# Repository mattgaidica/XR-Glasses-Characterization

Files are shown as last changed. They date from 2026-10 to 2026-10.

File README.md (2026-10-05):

# XR glasses characterization

Pipeline for controlled ocular photostimulation on a consumer see-through XR display (VITURE Luma Ultra): the stimulus application, the UPRtek acquisition and settings-to-exposure model, the calibration package, and the measurement data.

The validation manuscript and the scripts that rebuild it are not in this repository. Neither are the lab documents or the HOSI spectrometer pipeline.

## What is here

| Path | What it is |
|---|---|
| `apps/chronolume_host/` | Stimulus application. Build instructions are in its README. |
| `analysis/uprtek/` | UPRtek MK350S acquisition and the settings-to-exposure model. |
| `data/uprtek/model/` | Calibration package (`calibration.json`), validation report, and the [developer usage guide](data/uprtek/model/README.md). |
| `data/uprtek/` | The characterization, model, frame, and grid sessions. |
| `data/sessions/` | Host event logs for the characterization sessions. |
| `3d/` | Meter model (STEP). Added separately; this packaging script does not create it. |

`vendor/viture/` (the VITURE SDK) is not included. The host application links against it; see `apps/chronolume_host/README.md` and [VITURE](https://www.viture.com).

The mixture sessions `model_mixtures_s1_20261005_115533` and `model_mixtures_s2_20261005_120222` are included because `calibration.json` lists them in `training_sessions`. Earlier sessions from 2026-10-02 and 2026-10-03 are not: nothing in the manifest or the calibration package uses them.

## Run the analysis

Requires Python 3.11+.

```bash
python3 -m pip install -e "analysis/uprtek[analysis,dev]"
cd analysis/uprtek && python3 -m pytest
```

Predicting a uniform stimulus from the calibration package is described in `data/uprtek/model/README.md`.

## License

MIT. See `LICENSE`. The CIE tables under `analysis/uprtek/src/uprtek/data/cie/` stay under their own terms (`ATTRIBUTION.md` in that folder).

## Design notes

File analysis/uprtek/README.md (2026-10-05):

# Chronolume UPRtek capture and analysis

Automated spectral sweeps of the VITURE glasses with a UPRtek MK350S (Premium) on Windows, plus offline analysis.
This package is **independent of `analysis/hosi/`**: it imports nothing from HOSI and HOSI imports nothing from it. The CIE tables in `src/uprtek/data/cie/` are unchanged copies.

## What differs from HOSI

| | HOSI (`analysis/hosi`) | UPRtek (`analysis/uprtek`) |
|---|---|---|
| Raw data | C12880MA counts, per-row darks | Factory-calibrated spectral irradiance, 380–780 nm at 1 nm |
| Quantity | Radiance through lens/tube | Cosine-corrected **irradiance** at the probe plane |
| Absolute scale | `radSens` + transfer calibration | Instrument factory calibration |
| Corneal irradiance / α-opic | Needs an FOV assumption | Direct, with the probe at the eye position |
| Dark | Shutter dark at matching integration time | `mk_Msr_Dark` with the sensor capped |

`mk_GetSpectrum` returns **mW·m⁻²·nm⁻¹**. Every capture is checked by integrating the spectrum against V(λ) and comparing with the meter's own lux (`computed_to_instrument_lux_ratio`; mismatch > 3 % → `UNIT_CHECK_MISMATCH`, not quantitative).

## Setup (once)

The vendor `mkusb.dll` is 32-bit, so capture runs under 32-bit Python; analysis runs under 64-bit Python. From the repository root:

```powershell
py -3.12 -m venv .venv
.\.venv\Scripts\python -m pip install -e "analysis/uprtek[analysis,dev]"

py -3.12-32 -m venv .venv32
.\.venv32\Scripts\python -m pip install -e analysis/uprtek
```

Requires uSpectrum installed (`C:\Program Files (x86)\uSpectrum`), which provides `mkusb.dll` and the SiUSBXp driver. Override the DLL folder with `UPRTEK_MKUSB_DIR` or `--mkusb-dir`. **Close uSpectrum** before capturing; the meter allows one client.

Check the meter:

```powershell
.\.venv32\Scripts\python -m uprtek.probe
```

## Run a sweep

1. Glasses connected, desktop **extended** (Win+P → Extend). HDR, Night light, and Auto color management off for the glasses display. Dark room.
2. Start the host with the control port, fullscreen on the glasses monitor (indices are printed at startup):

   ```powershell
   .\build\apps\chronolume_host\Release\chronolume_host.exe --device viture --monitor 1 --control-port 7777
   ```

   Press `P` to fullscreen (or the sweep warns you).
3. Position the probe at the eye position and run:

   ```powershell
   .\.venv32\Scripts\python -m uprtek.sweep --sequence hosi_set --calibration-version uprtek_v001 --repeats 3
   ```

   For all channels alike (red, green, white and blue ladders and brightness sweeps), use `--sequence color_set --brightness 8`; `--brightness-levels 0,4,8` shortens it.

   The sweep asks you to cap the sensor for dark calibration, then uncap. The glasses show `(0,0,255)` during dark calibration so they do not sit dark through the prompts; `session.json` records how long `mk_Msr_Dark` itself took (`dark.duration_s`). It then presents each stimulus, waits for the host to confirm the frame was presented (with framebuffer readback), dwells `--settle-s`, and captures `--repeats` spectra. Every capture is also written into the host session log as a `mark` event.

Sequences (labels match the HOSI file names):

| `--sequence` | Steps |
|---|---|
| `hosi_set` (default) | `R255 G255 B255 W255`, blue ladder `B192…B016`, `K`, then `B255_br8…B255_br0` |
| `color_set` | `R255 G255 B255 W255`, blue ladder `B192…B016`, `K`, ladders `R/G/W 192 128 064`, then `R255 G255 B255 W255` at each of `--brightness-levels` (`R255_br8 … W255_br0`; no `W255_br8`, see *White at brightness 8*), then the duty block: `R255_d42 G255_d42 B255_d42 W255_br7_d42`, then the same at duty 30 (every duty preset below the base; see *Duty cycle*) |
| `primaries` | `R255 G255 B255 W255 K` |
| `blue_ladder` | `B016 B032 B064 B128 B192 B255` at the current brightness |
| `brightness_sweep` | `B255` at `--brightness-levels` (default `0-8`), highest first |
| `repeatability` | `B128 B255` (Gate 2: rerun after 20 min) |

`K` is subtracted from every capture in analysis and the dark reading drifts upward after dark calibration (see below), so it is taken right after the dimmest blue codes rather than first; a long black stretch was also followed by blanking on the next capture. Brightness sweeps run highest level first, so from base brightness 8 the first group and the level-8 anchors need no change. `color_set` characterizes red, green and white like blue, which the dose table needs (red, green and blue at level 8, white at its maximum of 7); the gamma and brightness fits in `uprtek-report` still use only the pure-blue points.

Useful options: `--eye left|right|both`, `--exposure auto|<ms>` (manual, at most 65 ms), `--max-exposure-ms N` (auto-exposure ceiling, see below), `--priming N` (discarded captures after each stimulus change, default 1; `0` saves time; a priming capture already at the exposure ceiling is kept as repeat 0, marked `kept_as_rep0` / `from_priming`), `--max-retries N` / `--retry-wait-s S` (re-capture when the display reads dark, default 5 / 2 s, see below), `--capture-retries N` (whole-capture re-runs, default 3), `--anchor-every N` (reference capture interval, default 5; `0` disables), `--duty 98|42|30|keep` (duty cycle held for the sweep, default 98; see *Duty cycle*), `--brightness N|keep` (hardware brightness for steps without their own, i.e. primaries, ladders and `K`, default 8; those steps return to it after a brightness sweep), `--brightness-change-rgb R,G,B` (shown while brightness changes, default `0,0,0`, see below), `--warmup-s 600` (Gate 2 warm-up on `(0,0,255)`), `--manual-brightness` (prompts you if the host cannot set brightness; captures are flagged `BRIGHTNESS_MANUAL`), `--allow-mock` (testing without glasses), `--skip-dark`.
Brightness is restored and the display set to black at the end, including on Ctrl-C.

### Low light: exposure

`mk_Msr_Capture` and `mk_Msr_SetMaxExpTime` take **microseconds** (the vendor guide says ms), and the reported `exposure_time_raw` is in µs. Manual exposure is therefore capped at 65 ms by the DLL's 16-bit argument, below the 500 ms auto-exposure ceiling, so it does not help with dim stimuli. Raise the auto-exposure ceiling instead, e.g. `--max-exposure-ms 5000` (verified on MK350X FW 1.1.1.B4: 5 s exposures, light strength 0). The ceiling persists on the meter, so the sweep and probe set it at the start and always restore 500 ms at the end; each capture records `max_exposure_ms`, and `range_cause` `low` means auto-exposure hit that ceiling. The sweep runs dark calibration after setting the ceiling. Check that the dark correction holds at long exposures before trusting dim readings: `.\.venv32\Scripts\python -m uprtek.probe --dark --max-exposure-ms 5000` with the sensor left capped should read close to 0 lux.

Output:

```text
data/uprtek/session_YYYYMMDD_HHMMSS/
  session.json        meter identity, host/device, options, dark time and duration, anchors, capture list, status
  raw/B255.csv        wavelength_nm, rep0, rep1, …  (mW/m²/nm, as returned by the meter)
  raw/B255.json       RGB, eye, brightness (+ source), duty cycle, film, display mode,
                      calibration version, host frame + readback, per-repeat meter readings
```

## Analyze

```powershell
.\.venv\Scripts\chronolume-uprtek analyze data/uprtek/session_YYYYMMDD_HHMMSS
.\.venv\Scripts\chronolume-uprtek linearity data/uprtek/session_.../analysis --x blue_code
.\.venv\Scripts\chronolume-uprtek linearity data/uprtek/session_.../analysis --x brightness
.\.venv\Scripts\chronolume-uprtek linearity data/uprtek/session_.../analysis --x duty
```

`linearity --x duty` fits a line to B255 at brightness 8 against duty cycle (the duty block plus the base-duty `B255`, duplicates averaged) and reports each duty as a fraction of the highest.

`linearity --x blue_code` fits a power law `y = y(255)·(B/255)^gamma` in log-log space to the quantitative blue-ladder captures and reports gamma, R² (log space) and each point's deviation from the fit. `linearity --x brightness` reports, for the `B255_br*` captures, the ratio between consecutive measured brightness levels (a disqualified level is skipped, and the step shows which levels it spans) and each level as a fraction of the brightest. Both write `linearity_<x>.json` and `.png` in the analysis folder. Both use pure-blue captures only; red, green and white captures from `color_set` are analyzed per capture but not yet fitted.

Per capture (`analysis/<label>/`): `spectrum.csv` (W/m²/nm, std across repeats, µW/cm²/nm, photons, and the increment over `K` when present), `summary.json`, `spectrum.png`, `spectrum_normalized.png`. A session table is written to `analysis/summary.csv`.

`summary.json` uses the HOSI key names where the quantity is the same (`peak_wavelength_nm`, `measured_fwhm_nm`, `spectral_centroid_nm`, `offband_fraction_500_780`, `irradiance_430_470_uW_cm2`, `photon_irradiance_photons_cm2_s`, `melanopic_EDI_lux`, …). Band integrals are irradiance (`irradiance_380_500_W_m2`, …), not radiance. `repeat_cv_percent` is the Gate 2 repeatability across repeats.

QC flags: `OUT_OF_RANGE`, `READBACK_MISMATCH`, `UNIT_CHECK_MISMATCH`, `NO_DISPLAY_LIGHT`, `REPEAT_OUTLIER`, `DUTY_MISMATCH`, `ANCHOR_DRIFT` (these make a capture non-quantitative), `LOW_LIGHT`, `REPEAT_CV_HIGH` (> 5 %), `WEAR_NOT_WORN` (the host reported the wear sensor as not worn at a repeat), `AMBIENT_PRESENT` (black > 1 % of the measurement), `FWHM_UNRESOLVED`, `PEAK_OUTSIDE_SEARCH`, `BRIGHTNESS_MANUAL`.

`OUT_OF_RANGE` means the meter returned light strength 2. The vendor guide calls that over exposure, but the MK350X (FW 1.1.1.B4) also returns it when the signal is too weak, so each repeat records a `range_cause`: `low` (auto-exposure pinned at its maximum), `saturated` (exposure ≤ 10 ms with ≥ 1 lux), or `unknown` (in darkness auto-exposure can also drop to a few ms, reading well under 1 lux).

**Blank display.** The glasses can blank intermittently during a sweep (even right after waking them). Turn off Wearer Detection on a phantom (see `apps/chronolume_host/README.md`); it was on for all sessions before 2026-10-03, off since. When the display blanks, the meter then reads its own dark noise, usually **without** light strength 2: a spectrum peaking above ~700 nm at a few tenths of a lux, typically at the exposure ceiling. Auto-exposure itself recovers correctly from long exposures (checked by switching black → B255 with a 5 s ceiling). The display primaries peak at 459, 539 and 631 nm, so for any non-black stimulus a peak ≥ 700 nm means no display light: the sweep discards that capture, waits `--retry-wait-s`, and re-captures, up to `--max-retries` times per repeat. Discarded attempts are kept under `rejected` in the raw JSON (with the host's `wear` value) and every attempt is a `mark` event. If the retries run out the capture is flagged `NO_DISPLAY_LIGHT`. A display that turns on part-way through a long exposure gives a low, blue-shifted reading that the peak test cannot see; `REPEAT_OUTLIER` (a repeat > 30 % from the capture median, checked when the median is ≥ 0.1 lux) catches it. `--priming` discarded captures (default 1) are recorded under `priming`.

**Stimulus visibility.** Before any capture (steps, re-runs and anchors) the host's framebuffer readback must match the requested RGB on a real framebuffer. A minimized stimulus window reads back 0×0 and zeros, which would otherwise pass for black; the glasses then show the desktop, and every stimulus measures the same. On a failed readback the sweep sends `fullscreen on`, then prompts you twice, then stops with an error. Failed readbacks that were fixed are kept under `readback_fixes`. The host no longer minimizes its fullscreen window when it loses focus, so this should be rare.

**Brightness changes on black.** Every brightness change (base level, brightness steps, anchors) is made with the display showing black; the stimulus is then re-presented and its readback checked before measuring. Raising brightness to 8 while full white was showing at duty 98 dropped the glasses' USB control link twice (SDK error -3, and every later command failed until the host was restarted). `--brightness-change-rgb 0,0,16` shows a dim blue instead, to keep the panel lit; it has not yet been tested against that USB drop. The sweep asks the host for the current level first and skips the change (and `--brightness-settle-s`) when the glasses already report it.

**White at brightness 8.** Full white `(255,255,255)` at brightness 8, duty 98, makes the Luma Ultra's output collapse (the next blue anchor read 0.47× and 0.09× of the reference in two sweeps on 2026-10-03) and then drops its USB control link (`get_brightness_level` returns -7, `set_duty_cycle` -3) until the host is restarted. It happens even when brightness is changed on black first. It is not specific to Windows or to duty 98: on macOS (firmware 12.0.01.101) at duty 90 on 2026-10-04, stepping white from 7 to 8 by hand returned SDK error -3, and an earlier attempt showed white at 8 briefly before the glasses' display dropped off the system. Red, green and blue alone are fine at 8, and white at 7 is fine. The sweep therefore never shows white (`r = g = b > 0`) above `WHITE_MAX_BRIGHTNESS` = 7: white steps that follow the base level (`W255`, the `W` ladder) run at 7 when the base is 8 and the next step returns to the base; with `--brightness keep` at 8 the same cap applies; sequences that ask for white above 7 explicitly are refused before anything is shown; and `color_set` has no `W255_br8`. Capped captures carry `white_brightness_capped: true` in their raw JSON, and the console line shows `(white capped at 7)`. Whether lower white codes (`W192`, …) are safe at 8 has not been tested. The host itself does not enforce the limit, so do not show white at 8 by hand.

**Re-running captures.** A capture that ends with `NO_DISPLAY_LIGHT` or `REPEAT_OUTLIER` is re-run in full (all repeats) up to `--capture-retries` times (default 3). Both triggers come from the capture's own readings, never from comparison with an expected value, so re-running does not steer results. Every discarded attempt is kept, with its spectra, under `discarded_attempts` in the raw JSON, and `capture_attempts` records how many were needed. If the last attempt still fails, the flag stays and the capture is not quantitative.

**Anchors.** A display that stays dim for a whole capture gives repeats that agree with each other, so the outlier check cannot see it. The sweep therefore captures an anchor, (0,0,255) at brightness 8, before the first step and after every `--anchor-every` steps (default 5; `0` disables). The first anchor is the reference; it must be clean or the sweep prompts you to check the glasses (three tries, then it stops). A later anchor more than 10 % from the reference is captured once more; if it is still off, the sweep pauses so you can wake the glasses or check the probe, then re-runs the steps since the previous anchor (twice at most). If it is still off after that, those captures are flagged `ANCHOR_DRIFT` and the sweep continues. Anchors are written to `anchors/raw/` (not `raw/`, so analysis ignores them) and summarised under `anchors` in `session.json`; block re-runs are listed under `block_reruns`. With `--brightness keep` brightness is restored after each anchor; otherwise the next step sets its own level (or the base level).

**Duty cycle.** The Luma Ultra supports only the manufacturer's SDK duty presets 98, 42 and 30 (`DUTY_PRESETS` in `sequences.py`); 98 is the base duty. `--duty` takes one of them (default 98) or `keep`, which leaves the glasses alone. When the sequence has steps with their own duty (`color_set`), the sweep first runs a duty check: it requests each preset with the display black and reads it back, and stops if any is not accepted. The result (every requested and reported value) is stored as `duty_acceptance` in `session.json`, and `color_set` builds its duty block from the presets below the base. The base duty is applied before the first capture and must read back, or the sweep stops. Duty is changed only on black, followed by `--brightness-settle-s`, and the steps after the duty block return to the base duty. The host re-reads duty after every brightness change; if it moved, the sweep re-applies it and records the old value as `duty_reapplied_from`. A capture whose host state does not show the requested duty (`requested_duty_cycle` in the raw JSON) is flagged `DUTY_MISMATCH`. The initial duty is restored at the end. Duty is a real intensity knob: at B255 and brightness 8, duty 30 gave ~41 % of the duty-90 output and duty 98 ~110 %. The host keys `,` / `.` (−10 / +10) and `9` (98) set duty by hand, e.g. for a photodiode check of the emitted waveform.

**Dark drift at long exposures.** With a 5 s ceiling the capped/blank reading drifted from 0.02 to ~0.5 lux over ~15 min after dark calibration. Measure dim stimuli soon after the dark step and keep `K` in the sequence so the analysis can subtract it; the built-in sequences take `K` right after the dimmest blue codes. Sessions recorded before this change carry the old name `OVER_EXPOSED`, which is still treated as disqualifying.

## Exposure model

A settings-to-exposure model predicts corneal melanopic EDI, photopic illuminance and melanopic DER for a uniform full-frame color at a brightness level and duty cycle, without measuring it (`docs/chronolume_exposure_model_developer_spec.md`), at the SDK duty presets.

### Capture (32-bit Python)

The grid is `src/uprtek/data/model_grid_v3.json` (schema `chronolume-model-grid/2`; `--grid` selects another, e.g. `model_grid_v2.json`, which keeps level 0 in the mixtures, or `model_grid_v1.json`), in three stages:

| `--stage` | Settings | Sessions |
|---|---|---|
| `primaries` | Code ladder: R, G, B at codes 64, 192, level 8, duty 98. Crossed: R, G at codes 128, 255 × levels 4, 8 × duties 30, 42, 98; B at 128, 255 × level 8 × the same duties, and B255 at level 4 × the same duties (39) | 3 |
| `ladders` | R, G, B at codes 64, 128, 192 × levels 2, 4, 5, 7 × duty 98 (36); code ladders below level 8, added after the primaries sessions showed that the code response depends on level | 3 |
| `mixtures` | 19 two- and three-channel compositions (gray axis, full white, pairs, unequal mixes) × levels 4, 7 × duties 30, 98 (76; level 0 dropped in v3, its mixtures fall near or below the meter's range) | 3 |
| `validation` | R, G, B at codes 96, 160 × levels 3, 6, and 6 new mixtures × levels 5, 6 (inside the mixtures' levels), all × duties 42, 98 (48); never used for fitting | 1 |

v2 replaces v1's primaries grid (codes 64–255 × levels 0, 4, 8 × duties 30, 42, 98: 108 settings), in which most settings were dim enough to sit at the exposure ceiling, retake for `NO_DISPLAY_LIGHT` and fall below the noise of their own black; the session was long enough to drift. v2 keeps every code at the bright state and crosses level and duty only where the signal is well above black (blue at level 4 is weak, so only code 255 runs there). The three v3 primaries sessions (2026-10-05) then showed that the code response is not shared across levels: code 128 gives 25–27 % of full-code output at level 8 but 9–11 % at level 4 (R, G), a power law with exponent about 2.0 at level 8 and 3.2–3.5 at level 4, and the full-code output rises slowly over levels 0–4 and steeply over 5–8 (two dimming regimes). The `ladders` stage measures the code response at levels 2, 4, 5 and 7 so each regime has its own ladders; validation primary levels 3 and 6 stay between ladder levels. The ladders sessions then showed that one power law per level fits level 8 but not the lower levels (code 64 at levels 2 and 4 was under-predicted by 40–72 %), so the code response is fitted as free nodes. The brightness response at the other levels comes from the `--reference` color_set sessions. Mixtures and validation are unchanged from v1. The presets leave no duty cycle between the calibrated ones, so validation tests unseen codes, levels and mixtures at calibrated duty cycles (the report's `duty_heldout` is false). Multi-channel stimuli never run above level 7, and white never above 7; a grid that asks for either is refused.

```powershell
.\.venv32\Scripts\chronolume-uprtek-model-sweep --stage primaries --dry-run
.\.venv32\Scripts\chronolume-uprtek-model-sweep --stage primaries --session-index 1 --seed 1 --calibration-version uprtek_v001 --wear-detection disabled
```

`--dry-run` prints the blocks and setting counts and exits. Capture is a separate entry point (not a `chronolume-uprtek` subcommand) because it runs under 32-bit Python with the meter. Settings are grouped into blocks of one (level, duty); each block starts and ends with black (`K_L4_D42_start`, `K_L4_D42_end`), which the fit subtracts. Block and setting order is a seeded permutation (`--seed`), reversed on even `--session-index` so drift is counterbalanced. The B255 anchor at level 8 and the base duty runs after each block's closing black (`--anchor-every block`, the default), so the hardware state never changes inside a block; `--anchor-every N` runs it every N settings instead, as before. A failed anchor is retaken once; two consecutive failed anchors stop the session. Each anchor sets level 8 and the base duty (duty on black) and checks both by readback before measuring, then restores the level and duty of the block that follows (or of the interrupted block, with `--anchor-every N`) on black and checks them by readback, stopping the session if either does not read back; the anchor record stores `anchor_state` and `restored_state`. Labels look like `C000-000-192_L4_D42`; each raw JSON adds `role`, `block_index`, `acquisition_order`, `model_stage`, `group` and `uniform_full_frame` to the usual state, and `session.json` (schema `chronolume-uprtek-model-session/1`) records the stage, seed, plan, `duty_acceptance`, `reseated` (`--not-reseated` to say otherwise) and `--wear-detection`. Reseat the glasses between sessions of a stage. Sessions are written to `data/uprtek/model_<stage>_<timestamp>/`.

### Fit, validate, predict (64-bit Python)

```powershell
.\.venv\Scripts\chronolume-uprtek model fit --calibration data/uprtek/model_primaries_* data/uprtek/model_ladders_* data/uprtek/model_mixtures_* --reference data/uprtek/session_<color_set> --calibration-id luma_ultra_v1 --output data/uprtek/model/calibration.json
.\.venv\Scripts\chronolume-uprtek model validate data/uprtek/model/calibration.json --validation data/uprtek/model_validation_* --output data/uprtek/model/validation.json
.\.venv\Scripts\chronolume-uprtek model predict data/uprtek/model/calibration.json --rgb 0,0,192 --level 4 --duty 42
```

Sessions without an `analysis/` folder are analyzed first. Outputs are display-attributable: each setting minus the mean of its block's blacks (`K` for `--reference` color_set sessions, which supply the full-code response at every brightness level). **Eligibility** is decided by the measurement alone, per output (`fit.py`): the capture is quantitative, its gross photopic reading is at least 1 lx (`PHOTOPIC_MIN_LUX`), and the output's net value is positive and at least `SIGNAL_TO_NOISE` (3) × its background noise, `max(|K_end − K_start|, BACKGROUND_REL_FLOOR (0.1) × mean K)` (reference color_set sessions have one `K`, so only the floor). For scoring, melanopic EDI must also be at least `MELANOPIC_MIN_EDI` (0.5 lx): red alone reads 0.1–0.3 lx melanopic EDI whatever its code, a meter floor. The same rule without that floor picks the fitting targets, so a dim red can enter the photopic fit but not the melanopic one, and a red at the melanopic floor still has parameters for the mixtures it is part of. In the metrics a prediction never decides eligibility: an eligible setting without a prediction is a failure (`n_failed`, which fails the targets), and a prediction below 1 lx stays in the errors and is counted (`n_pred_below_range`). Percentage errors are over eligible settings; `mae_all` (lx) is over every setting with a prediction; DER uses settings eligible for both outputs. Metrics carry `n_eligible` / `n_ineligible` per output, `by_group` (all, primary, mixture) and strata by group, composition (R, G, B, gray, RG, RB, GB, RGB_unequal), level and duty.

The six candidates are factorized (`a(code, level)·b(level)·q(duty)` per primary, with `a` a free code node at every code below 255 and level where it was measured: power-law segments between codes, log-linear in level between those "ladder levels", and below a level's lowest node the lowest segment extended toward code 0; codes below 255 are unsupported outside the ladder levels) and crossed (grid nodes per level and duty), each without a mixture interaction term, with the total form (`h = 1 − E·g` on the sum, `E` = drive above the strongest channel), and with the per-channel form (`+Hc`: each primary times `1 − O_c·g`, `O_c` = drive of the other channels), `g = β0 + βL·L/8 + βD·D/100` (ridge `INTERACTION_RIDGE` = 1e-3). A seventh, `factorized+Hc+Rder`, is `factorized+Hc` with red's melanopic parameters taken from its photopic ones times red's melanopic DER (geometric mean of melanopic EDI / photopic over red settings eligible for both outputs; code and duty responses shared): red's melanopic signal is at the meter floor, so its own melanopic code nodes drop out of some folds and leave dim-red mixtures unsupported (33 failed predictions on the nine sessions of 2026-10-05). The package records this as `model.melanopic_from_photopic` and each such primary's `melanopic_der`; prediction is unchanged. They are compared by leave-one-session-out cross-validation on the calibration sessions (each fold refits every parameter; reference sessions are fixed inputs), and the simplest one meeting the targets (MAPE ≤ 5 %, P95 ≤ 10 % for EDI and lux, no failed predictions) is chosen; if none does, the one with the fewest failed predictions and then the lowest worst-case MAPE is chosen with `meets_targets: false`. `selection.anchor_normalized` repeats the cross-validation with each calibration session scaled by the mean anchor of all sessions over its own (blue 255 at level 8); it is reported, never used for selection. The package's `fit` block records these rules and constants. `validate` only evaluates the locked package. It writes a report (metrics, candidate comparison, predictions with eligibility flags and composition, `validation_duties`, `duty_heldout`) and embeds a `validation` block in the package. Name that report as `model_report`, and the package as `model_package`, in `manuscripts/validation/data_manifest.json` to fill the manuscript's model section and Appendix A (parameter table, grids, candidate comparison, composition errors, reference estimator cases, the package's SHA-256, and a worked example that the build checks against `uprtek.model.forward`).

From code (stdlib only, no numpy):

```python
from uprtek.model.estimator import load_package, estimate

pkg = load_package("calibration.json")
estimate(pkg, rgb=(0, 0, 192), brightness_level=4, duty_setting=42,
         configuration={"firmware": "...", "film": "0.000000"})
```

Each result has `melanopic_edi_lx`, `photopic_lux`, `melanopic_der`, a `status`, a `support` (`measured`, `interpolated`, `extrapolated` when a code is below its channel's lowest node at that level, with a warning, `unsupported`), `targets_met` (with a warning when the package's model did not meet its targets), the package's empirical error, and `warnings`. Statuses: `configuration_mismatch` when a passed `configuration` differs from the package's device, firmware, product id, film or display mode (checked first); `unsupported` for codes below 255 at levels outside the ladder levels, levels or duty cycles outside the calibration, white above `white_max_level` and multi-channel stimuli above `multi_channel_max_level` or below `multi_channel_min_level` (the lowest mixture calibration level; the interaction term is not extrapolated) (code 0 is defined); `low_signal` when predicted photopic is below 1 lx (both values returned, no DER) or when only the melanopic prediction is outside its calibrated range (photopic returned, melanopic and DER not); `unavailable` without a valid package; otherwise `ok`. The only extrapolation is the code response below a level's lowest node.

`uprtek.model.experimental.estimate_frame_experimental(pkg, histogram, level, duty)` sums uniform estimates by pixel fraction for rendered frames. It is not validated (no whole-frame power limiting or spatial optical weighting) and always carries that warning.

## Application frames

Four example frames of what a custom app might show during photostimulation (`uprtek.frames`, stdlib only, rendered at the framebuffer size) test whether a frame's exposure can be read off its color histogram:

| Frame | Content | Level | Composed to the guidance |
|---|---|---|---|
| `F1_morning_text` | Bold blue (0,0,255) text on black, like the webapp's morning slides; 12 % lit | 8 | yes |
| `F2_orb` | Light-only orb: a blue disc the height of the frame stepping through codes 255, 192, 128, 64 toward its edge, on black; 44 % lit | 8 | yes |
| `F3_night_text` | The same slide in the webapp's night colors: (255,92,56) text on a (20,5,7) background | 5 | no (background below the lowest calibrated code) |
| `F4_red_orb` | The orb in red on black; 44 % lit | 5 | yes |

```powershell
.\.venv\Scripts\chronolume-uprtek-frames --out data/uprtek/frames/1920x1080
.\.venv32\Scripts\chronolume-uprtek-frame-sweep --dry-run
.\.venv32\Scripts\chronolume-uprtek-frame-sweep --session-index 1 --calibration-version uprtek_v001
.\.venv\Scripts\chronolume-uprtek-frame-check --characterization data/uprtek/session_<color_set> ... --package data/uprtek/model/calibration.json --frames data/uprtek/frames_s* --grid data/uprtek/grid_check.json --out data/uprtek/frames/frame_check.json
```

`--grid` (a `chronolume-uprtek-grid-check` report) adds a spatially weighted alternative, reported alongside the equal-weighting estimate and not validated (`uprtek.model.spatial`): a probe weight map (Gaussian plus offset, mean 1, fitted to the pooled red, green and blue photopic 3x3 map) and a lit-area gain `G(load) = load^-alpha`, with load the frame's mean summed photopic code response (a full-field primary is 1, full white 3) and alpha fitted to the grid's cell sums and full white over its primaries. `predicted.spatial` applies them to the model's uniform predictions, `measured.reference_spatial` to the same-block references (no model); the fitted terms are under `spatial`. On the 2026-10-05 sessions the four frames, 1.4–1.6× their equal-weighting estimates, come within −2 to +5 % (F3 melanopic +15 %, under 1 lx), from the grid alone. The weight map describes the phantom and probe, not a wearer's eye.

`chronolume-uprtek-frame-sweep` (32-bit Python, like the other sweeps) reads the framebuffer size from the host, renders the frames into `--frames-dir/<w>x<h>/` with `frames.json` (histograms and FNV-1a hashes), and sends each with the host's `image` command; a frame is measured only when the host's full-framebuffer readback matches it pixel for pixel (it retries `fullscreen on`, then prompts). Each frame is a block at its own level and the base duty: black, the frame, every non-black color in it as a uniform full-field reference (`F2_orb_U000-000-128`), black, then the B255 anchor, which also restores the next block's level. Even `--session-index` reverses the frame order. Raw JSON stores `stimulus: {kind: "image", path, hash, w, h}` with `rgb` set to the frame's main color for the analysis peak search, and `role`, `block_index`, `frame` and `acquisition_order`; `session.json` uses schema `chronolume-uprtek-frame-session/1`.

`chronolume-uprtek-frame-check` predicts each frame as the sum of uniform-color predictions over its histogram. With `--package` (the manuscript build passes `model_package` when the manifest has one) it uses the package's model, with the code response at the frame's level and the mixture interaction. Without it, it falls back to the characterization (color_set) sessions alone: the factorized forward model built from their display-attributable code ladders, brightness and duty steps, which applies the level-8 code response at every level and so overestimates low codes at the frames' level 5. Colors below the lowest calibrated code are not extrapolated: the frame then gets a lower bound (those pixels at 0) and an upper bound (at the lowest calibrated code) instead of an estimate. The report also gives the naive mean-RGB prediction (the whole frame as one uniform color), and, from frame sessions, the measured frame and the reference-weighted sum (each same-session uniform reference times its pixel fraction), all net of the block's mean black. A measured frame enters the comparison only when its capture is quantitative.

## Spatial grid check

Tests the assumption behind the frame predictions that the probe weights every pixel equally and that the display is additive in lit area. `uprtek.grid_frames` splits the framebuffer into a 3x3 grid (integer thirds) and lights one cell at a time at full code in R, G, B, or W on black, at level 7 (white's limit) and the base duty.

```powershell
.\.venv32\Scripts\chronolume-uprtek-grid-sweep --dry-run
.\.venv32\Scripts\chronolume-uprtek-grid-sweep --session-index 1 --max-exposure-ms 4000 --calibration-version uprtek_v001
.\.venv\Scripts\chronolume-uprtek-grid-check data/uprtek/grid_s* --out data/uprtek/grid_check.json
```

`chronolume-uprtek-grid-sweep` renders the 36 patterns into `--frames-dir/<w>x<h>/` (default `data/uprtek/grid_frames`) and shows them with the host's `image` command under the same pixel-for-pixel readback check as the frame sweep. One block per color: black, the uniform full field (`G_B255_FULL`), the nine cells center first (`G_B255_C`, `G_B255_TL`, …), black, then the B255 anchor. Even `--session-index` reverses the color order. Captures carry `role` (`black_start`, `full`, `cell`, `black_end`), `color` and `cell`; `session.json` uses schema `chronolume-uprtek-grid-session/1`.

`chronolume-uprtek-grid-check` nets every capture by its block's mean black and divides by the block's full field, for melanopic EDI and photopic illuminance: the relative weight `9 x cell / full` is 1.00 for every cell under equal weighting, and `sum of 9 / full` is 1.0 for an additive display (above 1.0 if small lit areas are driven brighter). It analyzes a temporary copy of each session, so nothing is written into the session folders.

## Tests

```powershell
cd analysis/uprtek
..\..\.venv\Scripts\python -m pytest
```

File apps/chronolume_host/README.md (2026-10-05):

# chronolume_host

The Chronolume stimulus application. It draws exact 8-bit RGB into a host window (the glasses as an extended display, or a mock window on the laptop) and independently sets/logs hardware brightness, electrochromic film, duty cycle, and display mode over USB. Runs on macOS and Windows.

Project overview: the [repository README](../../README.md). Scientific contract: [`docs/Chronolume_Project_Characterization_Gates.md`](../../docs/Chronolume_Project_Characterization_Gates.md).

## Build

From the repository root. Needs CMake, a C++17 compiler, and (on first configure) network access to fetch GLFW.

macOS:

```bash
cmake -S . -B build -DCMAKE_BUILD_TYPE=Release
cmake --build build -j
```

Windows (Visual Studio 2022 Build Tools, x64):

```powershell
cmake -S . -B build -G "Visual Studio 17 2022" -A x64
cmake --build build --config Release
```

The VITURE backend is compiled when the platform SDK library exists (`vendor/viture/macos/aarch64/libglasses.dylib` or `vendor/viture/windows/x86_64/glasses.dll`); otherwise the build is mock-only. The library is loaded at runtime from that folder, so nothing needs to be copied next to the executable.

## Run (no glasses)

```bash
./build/apps/chronolume_host/chronolume_host --device mock
```

On Windows the binary is `build\apps\chronolume_host\Release\chronolume_host.exe`.

| Option | Meaning |
|---|---|
| `--device mock\|viture` | Backend (default `mock`). |
| `--monitor N` | Monitor used by `P` / `fullscreen on`. Indices are printed at startup. Default: primary monitor. |
| `--control-port N` | Opt-in automation channel on `127.0.0.1:N` (see below). Keyboard control is unchanged. |

The terminal is the operator console. The window is the stimulus surface (fullscreen it onto the glasses display when hardware is present).

| Key | Action |
|---|---|
| `0`–`6` | Blue ladder: 0, 16, 32, 64, 128, 192, 255 |
| `K` `R` `G` `B` `W` | Black, red, green, blue, white |
| `F1` `F2` `F3` | Left eye, right eye, both (side-by-side halves) |
| `[` `]` | Brightness down / up (mock or SDK) |
| `,` `.` | Duty cycle down / up by 10, clamped to 0–100 (mock or SDK); requested and reported duty print to the console and log as a `duty` event |
| `9` | Duty cycle 98 (the SDK `H` preset) |
| `F` | Toggle electrochromic film |
| `S` | Start/stop session log |
| `D` | Print capability report |
| `V` | Read back framebuffer RGB (each half) |
| `P` | Fullscreen |
| `Esc` | Quit |

Session logs write to `data/sessions/`.

## With glasses

Extend the desktop onto the glasses (**do not mirror**; on Windows use Win+P → Extend). Move the stimulus window to that display, fullscreen it (or start with `--monitor N` and press `P`), then:

```bash
./build/apps/chronolume_host/chronolume_host --device viture
```

The SDK library is loaded only in this mode. If macOS blocks it, clear quarantine on the SDK libs:

```bash
xattr -dr com.apple.quarantine vendor/viture/macos/aarch64
```

On Windows, turn off HDR, Night light, and Auto color management for the glasses display so the panel receives the requested RGB unaltered. Check with `V` (framebuffer readback).

The SDK binaries stay on disk under `vendor/viture/macos/` and `vendor/viture/windows/` but are gitignored. Keep the original SDK zips as backup.

Do not use the SDK demo apps (`vendor/viture/*/demo/`); they are not part of this workflow.

## Control port

`--control-port N` accepts one localhost client and reads newline-terminated commands. Each command is answered with one JSON line **after the next frame has been presented**, including the full logged state (`r g b label eye brightness duty_cycle film display_mode wear calibration backend device`) and a framebuffer readback of both halves. Remote commands are recorded as `control` events in the active session log.

While an image is shown, the readback also carries `image: {w, h, hash, fb_hash, mismatched_pixels, match}`: the whole framebuffer is read back (top row first), compared with the image after eye masking, and both are hashed with FNV-1a 64 over the RGB bytes (`uprtek.frames.frame_hash` gives the same value). `mismatched_pixels` is -1 when the sizes differ.

`wear` is the glasses' wear sensor: `1` worn, `0` not worn, `-1` not reported (mock, or devices without wear detection). It is read at startup and updated from the SDK state callback; every change is printed and logged as a `wear` event. The display can blank when the sensor reports not worn, so check it when a capture reads dark. On a phantom, turn off Wearer Detection with the [VITURE firmware tool](https://www.viture.com/firmware/update) (the display otherwise turns off a minute after the glasses are "removed"); the SDK cannot read or change that setting. The lab Luma Ultra has had it off since 2026-10-03.

| Command | Effect |
|---|---|
| `ping` | Liveness check. |
| `info` | State plus firmware, product id, fullscreen, monitor, log path. |
| `rgb R G B [label]` | Full-field color (0–255). |
| `image <label> <path>` | Shows a binary PPM (P6, maxval 255) pixel for pixel, nearest-neighbour, with no color processing; the path is the rest of the line, so it may contain spaces. The image is stretched only if it is not the framebuffer size, which the readback then reports as a mismatch. Eye masking applies (the unshown half is black). The state's `r g b` read `0 0 0` while an image is shown, and `image` / `image_hash` name it; `rgb` clears it. |
| `eye left\|right\|both` | Side-by-side half selection (`F1`/`F2`/`F3`). |
| `brightness N` | Hardware brightness via the SDK (mock clamps 0–8). The duty cycle is re-read afterwards, so the reply shows whether the brightness change moved it. |
| `duty N` | Display duty cycle, 0–100 (the SDK's presets are 30, 42 and 98 = brightest). The reply and log carry the value the glasses report back. |
| `film on\|off` | Electrochromic film. |
| `calibration <version>` | Calibration tag logged with every stimulus event. |
| `fullscreen on\|off` | Same as `P`, on the `--monitor` display. |
| `log start [path]` / `log stop` | Session log (default path under `data/sessions/`). |
| `mark key=value …` | Writes a `mark` event with the current state (used to tie spectrometer captures to the log). |
| `quit` | Exit. |

Example session from PowerShell:

```powershell
$c = New-Object Net.Sockets.TcpClient('127.0.0.1', 7777); $s = $c.GetStream()
$w = New-Object IO.StreamWriter($s); $r = New-Object IO.StreamReader($s); $w.AutoFlush = $true
$w.WriteLine('rgb 0 0 255 B255'); $r.ReadLine()
```

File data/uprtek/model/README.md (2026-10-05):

# Developer usage guide: settings-to-exposure calibration

`calibration.json` is the calibration package (`luma_ultra_v1`) of the settings-to-exposure model in the validation manuscript (`manuscripts/validation/`, Section 2.5 and Appendix A). `validation.json` is its held-out validation report. The package predicts corneal-plane melanopic EDI, photopic illuminance and melanopic DER for a **uniform full-frame** color at a hardware brightness level and duty cycle on the VITURE Luma Ultra, in the configuration it records (device, firmware, product id, film state, display mode).

## Predicting a uniform stimulus

Load the full-precision package; do not transcribe the rounded parameter table in the manuscript.

```python
from uprtek.model.estimator import load_package, estimate

pkg = load_package("data/uprtek/model/calibration.json")
r = estimate(pkg, rgb=(0, 0, 192), brightness_level=4, duty_setting=42,
             configuration={"firmware": "...", "film": "0.000000"})
```

The estimator is stdlib only (`analysis/uprtek/src/uprtek/model/estimator.py`); Appendix A of the manuscript specifies the same algorithm for reimplementation, and an implementation should reproduce its reference cases. Values are display-attributable and exclude ambient light.

Check `status` and `support` before using a value:

| `status` | Meaning | Use |
|---|---|---|
| `ok` | Within the calibrated domain | Use the values |
| `low_signal` | Predicted photopic below 1 lx (both values, no DER), or melanopic outside its calibrated range (photopic only) | Use what is returned, with care |
| `unsupported` | Outside the calibrated domain | No value; choose another setting |
| `configuration_mismatch` | Passed configuration differs from the package's | No value; recalibrate or restore the configuration |

`support` is `measured`, `interpolated` or `extrapolated`. The only extrapolation is in code: a code below a channel's lowest code node at that level (code 64 for every channel) extends the lowest segment toward 0 and is flagged.

## Calibrated domain

- Brightness levels 0–8 for a full-code primary; codes below 255 only at levels 2–8.
- Duty cycles 30–98 (the device presets are 30, 42 and 98).
- Codes 64–255 per channel, plus 0 (off). Lower codes are extrapolated.
- Two- and three-channel colors, including white, only at levels 4–7. White is never shown above level 7: at level 8 it collapses the display and drops the USB control link.

## Composing rendered frames

The package covers uniform full-frame stimuli only. A rendered frame is outside the validated domain even when every color in it is supported.

- **Do not predict a frame from its mean color.** The code response is nonlinear; the mean color underestimated a blue orb's melanopic EDI 2.7-fold. The color histogram is the minimum input.
- **Sum over the histogram, but expect layout to matter.** The pixel-weighted sum of uniform predictions (`uprtek.model.experimental.estimate_frame_experimental`) read about a third low on the example frames, because the probe weights the center of the field and a small lit area gives more light per pixel than a full field.
- **Keep each color within the model's support.** Use a true black (0, 0, 0) background, pure primaries at codes 64–255 for light-carrying elements, and mixtures or white only at levels 4–7. Dark non-black backgrounds fall below the lowest calibrated code and can only be extrapolated.
- **Sparse content gives little light.** Bold blue text on black (12 % lit) was predicted at about a tenth of full-field blue; a frame meant to deliver a melanopic dose should light a large area.
- **Measure frames meant as stimuli.** The spatially weighted estimate (`uprtek.model.spatial`, `chronolume-uprtek-frame-check --grid`) is experimental: it was designed after the frames were measured, describes the phantom and probe rather than a wearer's eye, and is not validated. Until it is, measure such a frame on the rig.

Commands to refit, validate and check frames are in `analysis/uprtek/README.md` (Exposure model, Application frames, Spatial grid check).

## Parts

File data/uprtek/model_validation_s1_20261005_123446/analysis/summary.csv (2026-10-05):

label | rgb | eye | brightness_level | duty_cycle | quantitative | qc_flags | peak_wavelength_nm | measured_fwhm_nm | spectral_centroid_nm | irradiance_380_500_W_m2 | irradiance_380_780_W_m2 | irradiance_430_470_uW_cm2 | offband_fraction_500_780 | photon_irradiance_photons_cm2_s | photopic_illuminance_lux | instrument_lux | melanopic_EDI_lux | s_cone_opic_EDI_lux | repeat_cv_percent
C000-000-096_L3_D42 | 0 0 96 | both | 3 | 42 | True | LOW_LIGHT | 456 | 46.2439 | 575.009 | 0.00125436 | 0.00307711 | 0.0638794 | 0.592358 | 8.90721e+11 | 0.395024 | 0.395027 | 0.68902 | 0.884092 | 1.2817
C000-000-096_L3_D98 | 0 0 96 | both | 3 | 98 | True | LOW_LIGHT | 458 | 36.5548 | 515.282 | 0.00206236 | 0.0028687 | 0.13354 | 0.281081 | 7.44137e+11 | 0.255899 | 0.255901 | 1.1899 | 1.70445 | 0.0554749
C000-000-096_L6_D42 | 0 0 96 | both | 6 | 42 | True | LOW_LIGHT | 458 | 34.971 | 491.987 | 0.00771799 | 0.00922542 | 0.517959 | 0.163399 | 2.28488e+12 | 0.709861 | 0.709863 | 4.41817 | 6.5312 | 0.322576
C000-000-096_L6_D98 | 0 0 96 | both | 6 | 98 | True | LOW_LIGHT | 459 | 34.6623 | 476.468 | 0.0171312 | 0.0187014 | 1.16996 | 0.0839615 | 4.48571e+12 | 1.27937 | 1.27937 | 9.82619 | 14.6763 | 0.240898
C000-000-160_L3_D42 | 0 0 160 | both | 3 | 42 | True | LOW_LIGHT | 458 | 36.3047 | 528.299 | 0.00420974 | 0.00647918 | 0.265381 | 0.350267 | 1.72315e+12 | 0.635303 | 0.635307 | 2.38946 | 3.41361 | 0.213276
C000-000-160_L3_D98 | 0 0 160 | both | 3 | 98 | True | LOW_LIGHT | 459 | 34.9587 | 482.04 | 0.00860188 | 0.00968587 | 0.583167 | 0.111915 | 2.35042e+12 | 0.686502 | 0.686503 | 4.93705 | 7.33633 | 0.383762
C000-000-160_L6_D42 | 0 0 160 | both | 6 | 42 | True | LOW_LIGHT | 458 | 34.4943 | 473.703 | 0.0283613 | 0.0305366 | 1.94529 | 0.0712333 | 7.28198e+12 | 2.04719 | 2.04719 | 16.2042 | 24.3836 | 0.172635
C000-000-160_L6_D98 | 0 0 160 | both | 6 | 98 | True | LOW_LIGHT | 458 | 34.4611 | 470.293 | 0.0627809 | 0.0663293 | 4.32135 | 0.0534974 | 1.57035e+13 | 4.33539 | 4.33539 | 35.8969 | 54.1084 | 0.166751
C000-096-000_L3_D42 | 0 96 0 | both | 3 | 42 | True | LOW_LIGHT | 543 | 97.3398 | 585.085 | 0.000645638 | 0.003809 | 0.0163168 | 0.830496 | 1.1219e+12 | 1.13513 | 1.13513 | 0.712745 | 0.317281 | 0.930713
C000-096-000_L3_D98 | 0 96 0 | both | 3 | 98 | True | REPEAT_CV_HIGH LOW_LIGHT | 542 | 89.7971 | 565.287 | 0.000513131 | 0.00496226 | 0.00543492 | 0.896593 | 1.41212e+12 | 2.14204 | 2.14204 | 1.22653 | 0.205399 | 8.39562
C000-096-000_L6_D42 | 0 96 0 | both | 6 | 42 | True | LOW_LIGHT | 539 | 87.7436 | 558.412 | 0.00162351 | 0.0147702 | 0.0134529 | 0.890082 | 4.15207e+12 | 6.64044 | 6.64044 | 4.03613 | 0.628953 | 0.128944
C000-096-000_L6_D98 | 0 96 0 | both | 6 | 98 | True | LOW_LIGHT | 539 | 86.755 | 554.38 | 0.00322095 | 0.0317557 | 0.0152728 | 0.898571 | 8.86242e+12 | 14.9996 | 14.9996 | 9.03832 | 1.17939 | 0.0972419
C000-160-000_L3_D42 | 0 160 0 | both | 3 | 42 | True | LOW_LIGHT | 539 | 90.6191 | 569.989 | 0.00130957 | 0.00982024 | 0.0220145 | 0.866646 | 2.81781e+12 | 3.78128 | 3.78128 | 2.31892 | 0.5748 | 0.115454
C000-160-000_L3_D98 | 0 160 0 | both | 3 | 98 | True | LOW_LIGHT | 539 | 87.0218 | 556.613 | 0.00176188 | 0.017403 | 0.00979557 | 0.89876 | 4.87641e+12 | 8.08078 | 8.08077 | 4.81306 | 0.650085 | 0.271714
C000-160-000_L6_D42 | 0 160 0 | both | 6 | 42 | True | LOW_LIGHT | 538 | 86.1715 | 552.478 | 0.00523215 | 0.0500635 | 0.0245874 | 0.89549 | 1.39238e+13 | 23.8013 | 23.8013 | 14.5724 | 1.90935 | 0.122581
C000-160-000_L6_D98 | 0 160 0 | both | 6 | 98 | True | LOW_LIGHT | 539 | 85.7207 | 551.29 | 0.0112674 | 0.109775 | 0.0408845 | 0.897359 | 3.04654e+13 | 52.8916 | 52.8916 | 32.3722 | 4.04351 | 0.0313234
C000-192-096_L5_D42 | 0 192 96 | both | 5 | 42 | True | LOW_LIGHT | 539 | 87.5908 | 547.687 | 0.00761746 | 0.045049 | 0.246651 | 0.830907 | 1.24205e+13 | 19.7615 | 19.7615 | 13.7866 | 4.4047 | 0.243515
C000-192-096_L5_D98 | 0 192 96 | both | 5 | 98 | True | LOW_LIGHT | 539 | 87.3316 | 545.135 | 0.0164106 | 0.0976253 | 0.525699 | 0.831902 | 2.6791e+13 | 43.859 | 43.8589 | 30.632 | 9.4654 | 0.0775988
C000-192-096_L6_D42 | 0 192 96 | both | 6 | 42 | True | LOW_LIGHT | 539 | 87.4637 | 544.433 | 0.0149109 | 0.0841661 | 0.508344 | 0.822839 | 2.30677e+13 | 37.3341 | 37.3341 | 26.6304 | 8.84561 | 0.139121
C000-192-096_L6_D98 | 0 192 96 | both | 6 | 98 | True | LOW_LIGHT | 539 | 87.18 | 543.866 | 0.0322775 | 0.183288 | 1.09609 | 0.823898 | 5.01822e+13 | 81.8922 | 81.8922 | 58.2793 | 19.1249 | 0.0649423
C096-000-000_L3_D42 | 96 0 0 | both | 3 | 42 | True |  | 636 | 78.8953 | 623.806 | 0.000547782 | 0.00393918 | 0.0179896 | 0.86094 | 1.23703e+12 | 0.61835 | 0.618353 | 0.285727 | 0.29701 | 0.938022
C096-000-000_L3_D98 | 96 0 0 | both | 3 | 98 | True | LOW_LIGHT | 633 | 70.3497 | 642.765 | 0.00013779 | 0.00530617 | 0.00423114 | 0.974032 | 1.71695e+12 | 0.873589 | 0.87359 | 0.0882879 | 0.069844 | 2.29942
C096-000-000_L6_D42 | 96 0 0 | both | 6 | 42 | True | LOW_LIGHT | 632 | 81.5372 | 639.486 | 0.000369415 | 0.0120406 | 0.0115262 | 0.969319 | 3.87618e+12 | 2.11546 | 2.11546 | 0.228153 | 0.193769 | 0.0770686
C096-000-000_L6_D98 | 96 0 0 | both | 6 | 98 | True | LOW_LIGHT | 632 | 78.8162 | 642.398 | 0.000241716 | 0.0251231 | 0.0068579 | 0.990379 | 8.12458e+12 | 4.50421 | 4.50421 | 0.192476 | 0.118268 | 0.147416
C096-000-192_L5_D42 | 96 0 192 | both | 5 | 42 | True | LOW_LIGHT | 458 | 34.4626 | 507.034 | 0.0232014 | 0.0309925 | 1.58434 | 0.251387 | 7.91074e+12 | 2.73931 | 2.73932 | 13.2632 | 19.883 | 0.140987
C096-000-192_L5_D98 | 96 0 192 | both | 5 | 98 | True | LOW_LIGHT | 458 | 34.3633 | 501.443 | 0.0512173 | 0.0659478 | 3.52462 | 0.223367 | 1.66474e+13 | 5.64971 | 5.64971 | 29.3372 | 44.128 | 0.0266468
C096-000-192_L6_D42 | 96 0 192 | both | 6 | 42 | True | LOW_LIGHT | 458 | 34.4882 | 500.808 | 0.0443442 | 0.0568616 | 3.05084 | 0.220138 | 1.43355e+13 | 4.87839 | 4.87839 | 25.3592 | 38.2201 | 0.289231
C096-000-192_L6_D98 | 96 0 192 | both | 6 | 98 | True | LOW_LIGHT | 458 | 34.4126 | 499.151 | 0.0971902 | 0.123381 | 6.70082 | 0.212278 | 3.1003e+13 | 10.498 | 10.498 | 55.5633 | 83.8894 | 0.0440167
C096-096-096_L5_D42 | 96 96 96 | both | 5 | 42 | True | LOW_LIGHT | 459 | 220.847 | 573.639 | 0.0042215 | 0.0170961 | 0.232723 | 0.753072 | 4.93694e+12 | 4.46503 | 4.46503 | 3.82683 | 3.16715 | 0.0349015
C096-096-096_L5_D98 | 96 96 96 | both | 5 | 98 | True | LOW_LIGHT | 459 | 64.048 | 568.631 | 0.00879462 | 0.0350102 | 0.508549 | 0.748799 | 1.00219e+13 | 9.64757 | 9.64757 | 8.35005 | 6.82725 | 0.071102
C096-096-096_L6_D42 | 96 96 96 | both | 6 | 42 | True | LOW_LIGHT | 458 | 61.8986 | 564.599 | 0.00854794 | 0.0314144 | 0.492748 | 0.727898 | 8.92878e+12 | 8.61019 | 8.61019 | 7.87096 | 6.61441 | 0.199677
C096-096-096_L6_D98 | 96 96 96 | both | 6 | 98 | True | LOW_LIGHT | 459 | 60.5405 | 563.017 | 0.0186312 | 0.06801 | 1.09157 | 0.726053 | 1.9276e+13 | 18.939 | 18.939 | 17.37 | 14.5745 | 0.1818
C160-000-000_L3_D42 | 160 0 0 | both | 3 | 42 | True | LOW_LIGHT | 627 | 84.2172 | 634.163 | 0.00060555 | 0.00867543 | 0.0180351 | 0.930199 | 2.76959e+12 | 1.45044 | 1.45044 | 0.331712 | 0.31239 | 0.115928
C160-000-000_L3_D98 | 160 0 0 | both | 3 | 98 | True | LOW_LIGHT | 628 | 77.1807 | 643.063 | 0.000172777 | 0.0149596 | 0.00540149 | 0.98845 | 4.8428e+12 | 2.61862 | 2.61862 | 0.133042 | 0.0914272 | 0.249291
C160-000-000_L6_D42 | 160 0 0 | both | 6 | 42 | True | LOW_LIGHT | 631 | 79.9873 | 641.565 | 0.000283815 | 0.0369018 | 0.00884761 | 0.992309 | 1.19182e+13 | 6.84816 | 6.84816 | 0.263812 | 0.147556 | 0.210316
C160-000-000_L6_D98 | 160 0 0 | both | 6 | 98 | True | LOW_LIGHT | 631 | 79.6311 | 642.192 | 0.000199259 | 0.0808538 | 0.00678135 | 0.997536 | 2.6139e+13 | 15.074 | 15.074 | 0.347323 | 0.109617 | 0.130573
C160-160-160_L5_D42 | 160 160 160 | both | 5 | 42 | True | LOW_LIGHT | 459 | 61.4134 | 562.419 | 0.0153505 | 0.0550504 | 0.89456 | 0.721155 | 1.55863e+13 | 15.243 | 15.2429 | 14.1587 | 11.9693 | 0.0740047
C160-160-160_L5_D98 | 160 160 160 | both | 5 | 98 | True | LOW_LIGHT | 458 | 59.8616 | 560.892 | 0.033548 | 0.119174 | 1.97385 | 0.718497 | 3.365e+13 | 33.3994 | 33.3994 | 31.1529 | 26.3201 | 0.0535762
C160-160-160_L6_D42 | 160 160 160 | both | 6 | 42 | True | LOW_LIGHT | 458 | 59.7899 | 558.697 | 0.0304417 | 0.104667 | 1.79323 | 0.709156 | 2.9438e+13 | 29.4025 | 29.4025 | 28.032 | 23.9054 | 0.105228
C160-160-160_L6_D98 | 160 160 160 | both | 6 | 98 | True | LOW_LIGHT | 458 | 59.4241 | 558.322 | 0.0657585 | 0.22576 | 3.88373 | 0.708723 | 6.34533e+13 | 63.6517 | 63.6517 | 60.7092 | 51.7279 | 0.0592105
C192-096-000_L5_D42 | 192 96 0 | both | 5 | 42 | True | LOW_LIGHT | 629 | 83.6973 | 626.407 | 0.000996928 | 0.0380109 | 0.0145162 | 0.973773 | 1.19864e+13 | 8.89682 | 8.89683 | 2.11089 | 0.426561 | 0.0920173
C192-096-000_L5_D98 | 192 96 0 | both | 5 | 98 | True | LOW_LIGHT | 631 | 81.8489 | 627.059 | 0.00150339 | 0.0820739 | 0.0103564 | 0.981682 | 2.59082e+13 | 19.4476 | 19.4476 | 4.30146 | 0.572737 | 0.0957185
C192-096-000_L6_D42 | 192 96 0 | both | 6 | 42 | True | LOW_LIGHT | 629 | 83.1294 | 625.274 | 0.00153278 | 0.0690549 | 0.0139439 | 0.977803 | 2.17364e+13 | 16.6696 | 16.6696 | 4.00429 | 0.607607 | 0.112807
C192-096-000_L6_D98 | 192 96 0 | both | 6 | 98 | True | LOW_LIGHT | 630 | 82.2843 | 625.487 | 0.00294047 | 0.150224 | 0.0182029 | 0.980426 | 4.73023e+13 | 36.4044 | 36.4044 | 8.49969 | 1.1072 | 0.096599
C192-096-080_L5_D42 | 192 96 80 | both | 5 | 42 | True | LOW_LIGHT | 631 | 82.9954 | 618.69 | 0.00294355 | 0.0398683 | 0.14899 | 0.926168 | 1.24172e+13 | 8.92092 | 8.92092 | 3.18213 | 2.10681 | 0.173925
C192-096-080_L5_D98 | 192 96 80 | both | 5 | 98 | True | LOW_LIGHT | 631 | 81.7741 | 619.108 | 0.00579956 | 0.0858641 | 0.309112 | 0.932456 | 2.67609e+13 | 19.447 | 19.447 | 6.66021 | 4.30086 | 0.173782
C192-096-080_L6_D42 | 192 96 80 | both | 6 | 42 | True | LOW_LIGHT | 631 | 82.5659 | 616.233 | 0.00565832 | 0.0726507 | 0.301897 | 0.922116 | 2.25376e+13 | 16.6699 | 16.6699 | 6.26763 | 4.18894 | 0.0554054
C192-096-080_L6_D98 | 192 96 80 | both | 6 | 98 | True | LOW_LIGHT | 631 | 82.3984 | 616.483 | 0.0119055 | 0.157836 | 0.642144 | 0.92457 | 4.89836e+13 | 36.3372 | 36.3371 | 13.4285 | 8.89147 | 0.0991343
K_L3_D42_end | 0 0 0 | both | 3 | 42 | True | LOW_LIGHT | 772 | 125.217 | 604.981 | 0.00061508 | 0.00246129 | 0.0203867 | 0.750099 | 7.49598e+11 | 0.362738 | 0.362741 | 0.313134 | 0.336091 | 1.62583
K_L3_D42_start | 0 0 0 | both | 3 | 42 | True | LOW_LIGHT | 776 | 123.983 | 606.628 | 0.000428949 | 0.00174814 | 0.0138363 | 0.754626 | 5.33854e+11 | 0.257087 | 0.25709 | 0.221276 | 0.231572 | 1.58324
K_L3_D98_end | 0 0 0 | both | 3 | 98 | True | LOW_LIGHT | 772 | 22.2891 | 608.238 | 7.18372e-05 | 0.000308024 | 0.00221107 | 0.766781 | 9.43153e+10 | 0.0473727 | 0.047373 | 0.0395863 | 0.0370981 | 3.6623
K_L3_D98_start | 0 0 0 | both | 3 | 98 | True | REPEAT_CV_HIGH LOW_LIGHT | 726 | 3.22406 | 606.864 | 5.36258e-06 | 2.82093e-05 | 7.40463e-05 | 0.8099 | 8.61801e+09 | 0.00497559 | 0.0049756 | 0.00311124 | 0.00157221 | 89.9203
K_L5_D42_end | 0 0 0 | both | 5 | 42 | True | LOW_LIGHT | 775 | 23.2435 | 606.332 | 0.000382174 | 0.00154763 | 0.0127568 | 0.753059 | 4.72391e+11 | 0.227968 | 0.22797 | 0.198194 | 0.20971 | 1.99132
K_L5_D42_start | 0 0 0 | both | 5 | 42 | True | LOW_LIGHT | 776 | 23.1508 | 606.493 | 0.000308927 | 0.0012512 | 0.00998091 | 0.753097 | 3.82012e+11 | 0.181623 | 0.181625 | 0.155945 | 0.164256 | 1.78332
K_L5_D98_end | 0 0 0 | both | 5 | 98 | True | LOW_LIGHT | 385 |  | 606.891 | 0.000103673 | 0.000410009 | 0.00316407 | 0.747143 | 1.25264e+11 | 0.0564517 | 0.0564523 | 0.0481588 | 0.0509092 | 2.14337
K_L5_D98_start | 0 0 0 | both | 5 | 98 | True | LOW_LIGHT | 764 | 22.1368 | 611.281 | 7.51433e-05 | 0.000330697 | 0.00225237 | 0.772773 | 1.01764e+11 | 0.0491712 | 0.0491716 | 0.0409167 | 0.0386118 | 1.16199
K_L6_D42_end | 0 0 0 | both | 6 | 42 | True | LOW_LIGHT | 776 | 23.0858 | 606.634 | 0.000270389 | 0.00109482 | 0.00875838 | 0.75303 | 3.34344e+11 | 0.159992 | 0.159993 | 0.135721 | 0.143552 | 2.66632
K_L6_D42_start | 0 0 0 | both | 6 | 42 | True | LOW_LIGHT | 385 |  | 606.076 | 0.000187842 | 0.000735077 | 0.00593343 | 0.744459 | 2.24276e+11 | 0.1013 | 0.101301 | 0.0894636 | 0.0975769 | 2.81507
K_L6_D98_end | 0 0 0 | both | 6 | 98 | True | LOW_LIGHT | 759 | 22.9561 | 604.337 | 0.000156818 | 0.000624227 | 0.00477211 | 0.74878 | 1.89909e+11 | 0.0940606 | 0.0940614 | 0.0798872 | 0.0828759 | 2.90511
K_L6_D98_start | 0 0 0 | both | 6 | 98 | True | LOW_LIGHT | 740 | 29.2091 | 605.876 | 0.000118886 | 0.000462911 | 0.00352848 | 0.743177 | 1.4119e+11 | 0.0625148 | 0.0625155 | 0.0561207 | 0.0591054 | 1.43131

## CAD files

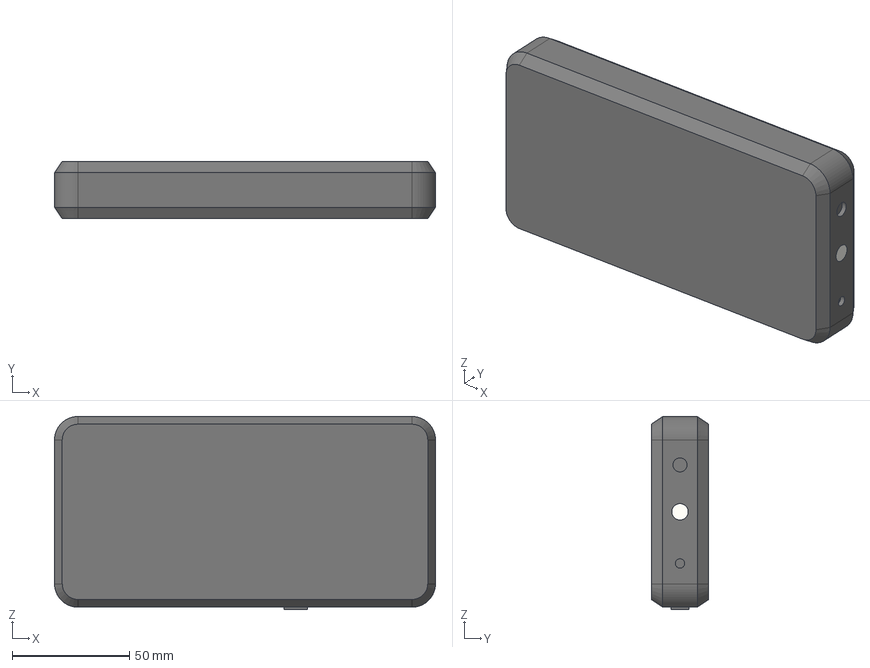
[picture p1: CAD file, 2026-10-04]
3d/UPRtek MK350S.step
162.4 x 24.5 x 82.3 mm

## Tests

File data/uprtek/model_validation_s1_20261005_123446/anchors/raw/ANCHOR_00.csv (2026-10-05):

wavelength_nm | rep0 | rep1 | rep2
380 | 1.32431583e-02 | 4.77271620e-03 | 0.00000000e+00
381 | 1.32431583e-02 | 4.77271620e-03 | 0.00000000e+00
382 | 1.32431583e-02 | 4.77271620e-03 | 0.00000000e+00
383 | 1.15742162e-02 | 3.96722229e-03 | 0.00000000e+00
384 | 8.26732721e-03 | 2.37631635e-03 | 1.27326857e-05
385 | 4.53454768e-03 | 7.85411044e-04 | 5.36144245e-04
386 | 2.04482093e-03 | 0.00000000e+00 | 1.57023466e-03
387 | 1.21619110e-03 | 0.00000000e+00 | 2.69387895e-03
388 | 1.51137181e-03 | 0.00000000e+00 | 2.79543386e-03
389 | 2.93036248e-03 | 0.00000000e+00 | 1.87489996e-03
390 | 5.03477920e-03 | 0.00000000e+00 | 7.38523086e-04
391 | 7.15288799e-03 | 0.00000000e+00 | 1.13556474e-04
392 | 9.15620103e-03 | 6.51466107e-05 | 4.88601363e-05
393 | 1.03602838e-02 | 5.37062180e-04 | 4.02798178e-04
394 | 1.07620973e-02 | 1.41574699e-03 | 1.06181414e-03
395 | 1.01865232e-02 | 2.19138898e-03 | 1.64354779e-03
396 | 9.05507524e-03 | 2.15288415e-03 | 1.61466922e-03
397 | 7.36775016e-03 | 1.30023248e-03 | 9.75177856e-04
398 | 6.28191745e-03 | 4.59443865e-04 | 4.32946748e-04
399 | 6.10813452e-03 | 2.60330289e-05 | 2.90644908e-04
400 | 6.99621812e-03 | 3.66172928e-04 | 5.77495899e-04
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

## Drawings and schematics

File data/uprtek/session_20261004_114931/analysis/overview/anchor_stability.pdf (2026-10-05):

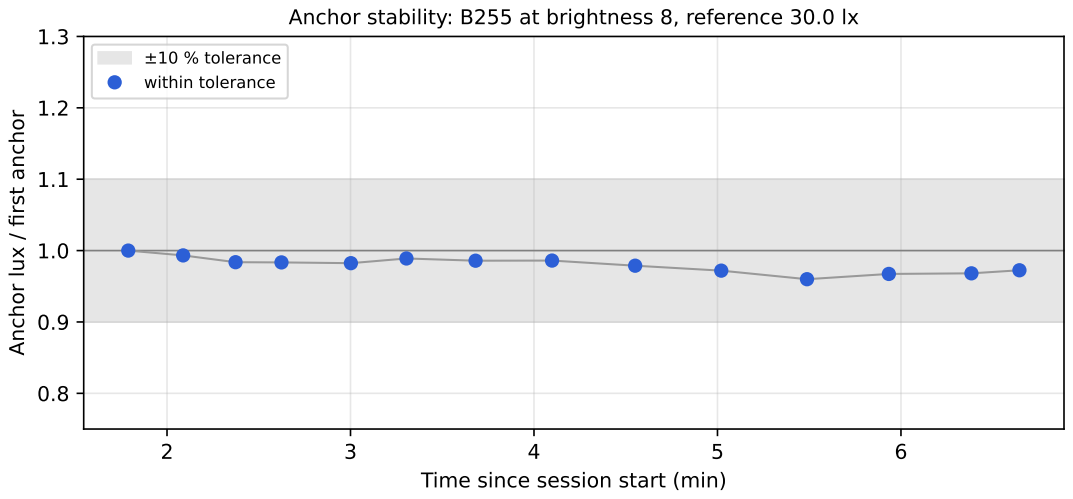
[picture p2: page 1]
Anchor lux /; first anchor; ±10 % tolerance; within tolerance

Anchor stability: B255 at brightness 8, reference 30.0 lx

Time since session start (min)

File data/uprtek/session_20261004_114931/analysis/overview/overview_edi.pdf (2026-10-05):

300

400

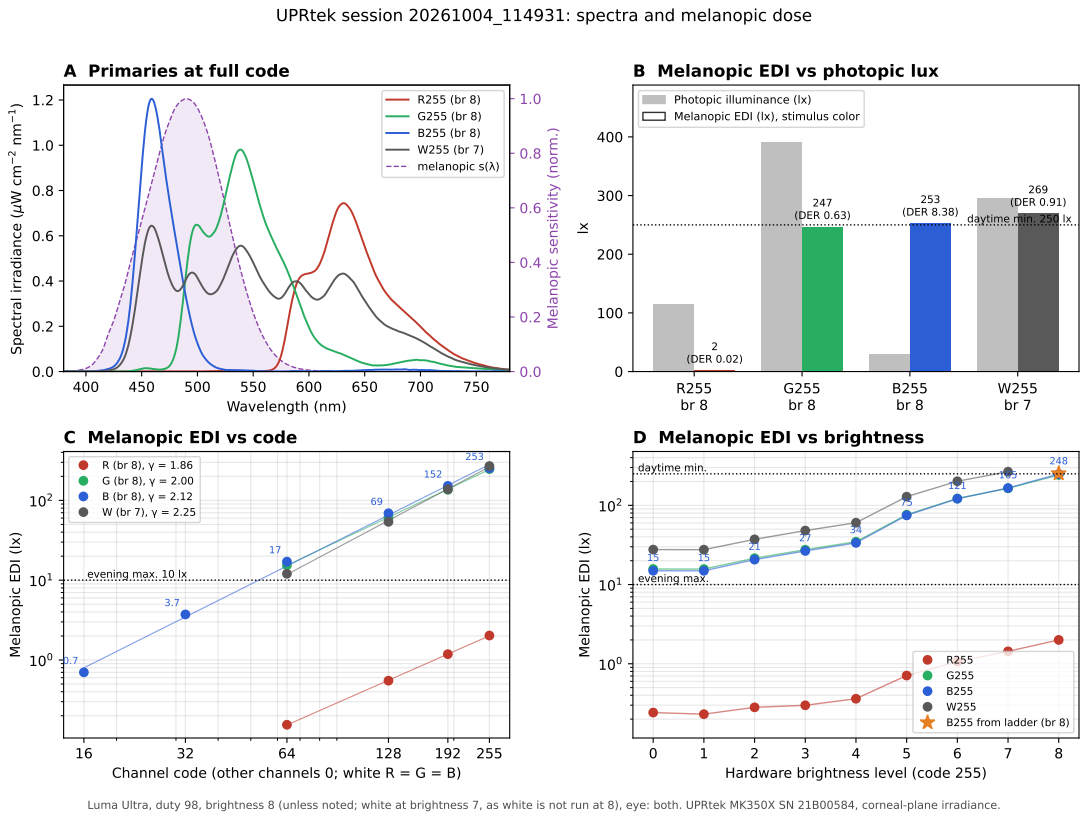
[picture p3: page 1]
2 (DER 0.02); 247 (DER 0.63); 253 (DER 8.38); 269 (DER 0.91) daytime min. 250 lx; Wavelength (nm); ectral irra; dia; nce (μ; R255 (br 8) G255 (br 8) B255 (br 8) W255 (br 7) melanopic s(λ)

UPRtek session 20261004_114931: spectra and melanopic dose

A Primaries at full code

B Melanopic EDI vs photopic lux
Photopic illuminance (lx)
Melanopic EDI (lx), stimulus color

Melanopic sensitivity (norm.)

C Melanopic EDI vs code

D Melanopic EDI vs brightness

R (br 8), γ = 1.86 | | | 253
G (br 8), γ = 2.00 B (br 8), γ = 2.12 | 69

248 daytime min.

Melanopic EDI (lx)

15 | 15
evening max.

evening max. 10 lx

R255
G255
B255
W255

B255 from ladder (br 8)

Channel code (other channels 0; white R = G = B)

Hardware brightness level (code 255)

Luma Ultra, duty 98, brightness 8 (unless noted; white at brightness 7, as white is not run at 8), eye: both. UPRtek MK350X SN 21B00584, corneal-plane irradiance.

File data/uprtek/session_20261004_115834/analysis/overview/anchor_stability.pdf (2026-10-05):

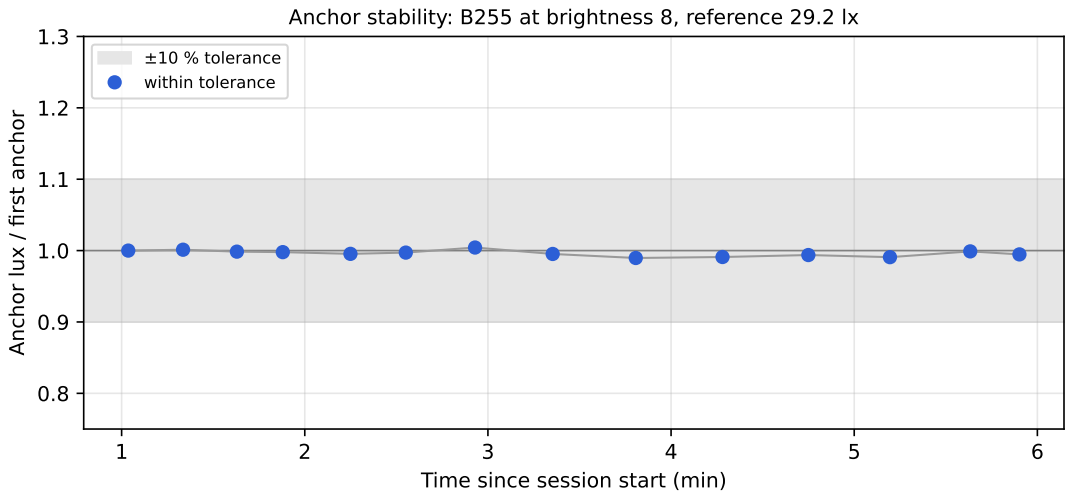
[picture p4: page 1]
Anchor lux /; first anchor; ±10 % tolerance; within tolerance

Anchor stability: B255 at brightness 8, reference 29.2 lx

Time since session start (min)

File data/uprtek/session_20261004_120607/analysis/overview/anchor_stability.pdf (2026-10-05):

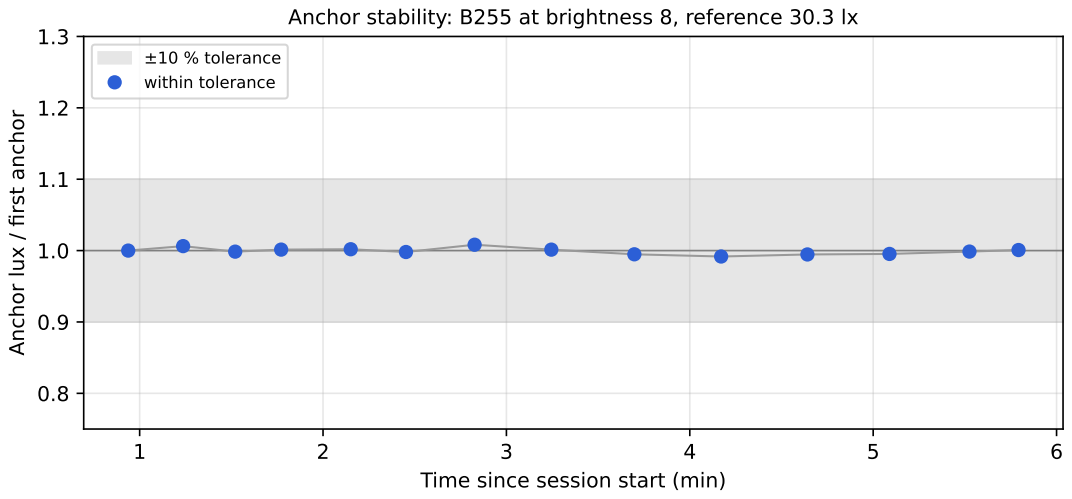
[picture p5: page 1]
Anchor lux /; first anchor; ±10 % tolerance; within tolerance

Anchor stability: B255 at brightness 8, reference 30.3 lx

Time since session start (min)

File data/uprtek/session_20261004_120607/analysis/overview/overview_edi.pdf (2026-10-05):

300

400

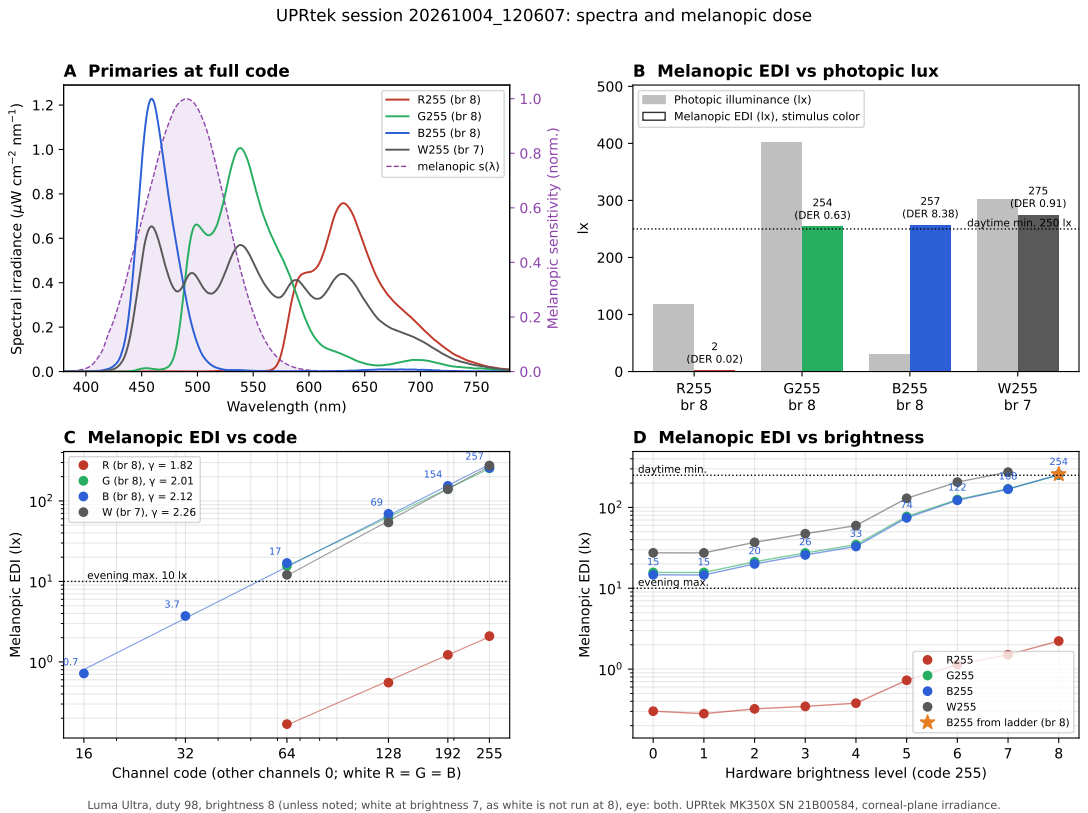
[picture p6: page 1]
2 (DER 0.02); 254 (DER 0.63); 257 (DER 8.38); 275 (DER 0.91) daytime min. 250 lx; evening max. 10 lx; Wavelength (nm); ectral irra; dia; nce (μ; R255 (br 8) G255 (br 8) B255 (br 8) W255 (br 7) melanopic s(λ)

UPRtek session 20261004_120607: spectra and melanopic dose

A Primaries at full code

B Melanopic EDI vs photopic lux

Photopic illuminance (lx)
Melanopic EDI (lx), stimulus color

Melanopic sensitivity (norm.)

C Melanopic EDI vs code

D Melanopic EDI vs brightness
254 daytime min.

Melanopic EDI (lx)

15 | 15
evening max.

R255
G255
B255
W255
B255 from ladder (br 8)

Channel code (other channels 0; white R = G = B)

Hardware brightness level (code 255)

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

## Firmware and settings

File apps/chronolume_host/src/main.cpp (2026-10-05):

#include "control/control_server.hpp"
#include "device/device.hpp"
#include "display/frame_image.hpp"
#include "display/macos_colorspace.h"
#include "display/stimulus.hpp"
#include "logging/session_log.hpp"

#include <GLFW/glfw3.h>

#ifdef __APPLE__
#include <OpenGL/gl.h>
#else
#include <GL/gl.h>
#endif

#ifndef GL_CLAMP_TO_EDGE
#define GL_CLAMP_TO_EDGE 0x812F
#endif

#include <chrono>
#include <cstdio>
#include <cstdlib>
#include <cstring>
#include <ctime>
#include <filesystem>
#include <map>
#include <memory>
#include <sstream>
#include <string>
#include <vector>

namespace {

constexpr uint8_t kBlueLadder[] = {0, 16, 32, 64, 128, 192, 255};

struct App {
    std::unique_ptr<Device> device;
    StimulusState stimulus;
    SessionLog log;
    std::string calibration_version = "uncalibrated";
    bool dirty = true;
    ControlServer control;
    std::string remote_label;
    int monitor_index = -1;
    uint64_t frame = 0;
    int last_wear = -2;
    FrameImage image;
    unsigned int image_tex = 0;
};

void print_keys() {
    std::puts("Chronolume host — terminal is the operator console.");
    std::puts("  0-6     blue ladder 0, 16, 32, 64, 128, 192, 255");
    std::puts("  K R G B W   black / red / green / blue255 / white");
    std::puts("  F1 F2 F3    left / right / both eyes (SBS halves)");
    std::puts("  [ ]     brightness down / up");
    std::puts("  , .     duty cycle down / up by 10 (0-100)");
    std::puts("  9       duty cycle 98 (SDK H preset)");
    std::puts("  F       toggle electrochromic film");
    std::puts("  S       start/stop session log");
    std::puts("  D       capability dump");
    std::puts("  V       read back framebuffer RGB (each half)");
    std::puts("  P       fullscreen");
    std::puts("  Esc     quit");
}

void print_info(const DeviceInfo& info) {
    std::printf("backend      %s\n", info.backend.c_str());
    std::printf("name         %s\n", info.market_name.c_str());
    std::printf("product_id   0x%04X\n", info.product_id);
    std::printf("device_type  %d\n", info.device_type);
    std::printf("firmware     %s\n", info.firmware.c_str());
    std::printf("display_mode 0x%02X\n", info.display_mode);
    std::printf("brightness   %d\n", info.brightness);
    std::printf("duty_cycle   %d\n", info.duty_cycle);
    std::printf("film         %.3f\n", info.film);
    std::printf("wear         %d\n", info.wear_status);
    std::printf("connected    %s\n", info.connected ? "yes" : "no");
    if (!info.last_error.empty()) {
        std::printf("error        %s\n", info.last_error.c_str());
    }
}

std::map<std::string, std::string> stimulus_fields(const App& app) {
    const DeviceInfo info = app.device->info();
    return {
        {"r", std::to_string(app.stimulus.r)},
        {"g", std::to_string(app.stimulus.g)},
        {"b", std::to_string(app.stimulus.b)},
        {"label", app.stimulus.label},
        {"eye", eye_name(app.stimulus.eye)},
        {"brightness", std::to_string(info.brightness)},
        {"duty_cycle", std::to_string(info.duty_cycle)},
        {"film", std::to_string(info.film)},
        {"display_mode", std::to_string(info.display_mode)},
        {"wear", std::to_string(info.wear_status)},
        {"calibration", app.calibration_version},
        {"backend", info.backend},
        {"device", info.market_name},
        {"image", app.stimulus.image ? app.image.path : ""},
        {"image_hash", app.stimulus.image ? hex64(app.image.hash) : ""},
    };
}

std::string stimulus_desc(const App& app) {
    if (app.stimulus.image) {
        return "image " + std::to_string(app.image.w) + "x" + std::to_string(app.image.h) + " " +
               hex64(app.image.hash);
    }
    return rgb_string(app.stimulus);
}

void log_stimulus(App* app) {
    if (app->log.active()) {
        app->log.event("stimulus", stimulus_fields(*app));
    }
    const DeviceInfo info = app->device->info();
    std::printf("stimulus %s %s  eye=%s  bri=%d duty=%d film=%.0f\n",
                app->stimulus.label, stimulus_desc(*app).c_str(),
                eye_name(app->stimulus.eye), info.brightness, info.duty_cycle,
                info.film);
}

void draw_half(float x0, float x1, uint8_t r, uint8_t g, uint8_t b) {
    const GLubyte px[3] = {r, g, b};
    glTexImage2D(GL_TEXTURE_2D, 0, GL_RGB8, 1, 1, 0, GL_RGB, GL_UNSIGNED_BYTE, px);
    glBegin(GL_QUADS);
    glTexCoord2f(0, 0);
    glVertex2f(x0, -1);
    glTexCoord2f(1, 0);
    glVertex2f(x1, -1);
    glTexCoord2f(1, 1);
    glVertex2f(x1, 1);
    glTexCoord2f(0, 1);
    glVertex2f(x0, 1);
    glEnd();
}

void set_nearest_clamp() {
    glTexParameteri(GL_TEXTURE_2D, GL_TEXTURE_MIN_FILTER, GL_NEAREST);
    glTexParameteri(GL_TEXTURE_2D, GL_TEXTURE_MAG_FILTER, GL_NEAREST);
    glTexParameteri(GL_TEXTURE_2D, GL_TEXTURE_WRAP_S, GL_CLAMP_TO_EDGE);
    glTexParameteri(GL_TEXTURE_2D, GL_TEXTURE_WRAP_T, GL_CLAMP_TO_EDGE);
}

// The image's top row is texture row 0, so t runs from 1 at the bottom edge to 0 at the top.
void draw_image_half(float x0, float x1, float s0, float s1) {
    glBegin(GL_QUADS);
    glTexCoord2f(s0, 1);
    glVertex2f(x0, -1);
    glTexCoord2f(s1, 1);
    glVertex2f(x1, -1);
    glTexCoord2f(s1, 0);
    glVertex2f(x1, 1);
    glTexCoord2f(s0, 0);
    glVertex2f(x0, 1);
    glEnd();
}

void render_stimulus(const StimulusState& s, unsigned int color_tex, unsigned int image_tex) {
    glDisable(GL_BLEND);
    glDisable(GL_DEPTH_TEST);
    glEnable(GL_TEXTURE_2D);

    const bool left_on = s.eye == EyeTarget::Left || s.eye == EyeTarget::Both;
    const bool right_on = s.eye == EyeTarget::Right || s.eye == EyeTarget::Both;
    if (s.image) {
        glBindTexture(GL_TEXTURE_2D, image_tex);
        set_nearest_clamp();
        if (left_on) {
            draw_image_half(-1.0f, 0.0f, 0.0f, 0.5f);
        }
        if (right_on) {
            draw_image_half(0.0f, 1.0f, 0.5f, 1.0f);
        }
        glBindTexture(GL_TEXTURE_2D, color_tex);
        set_nearest_clamp();
        if (!left_on) {
            draw_half(-1.0f, 0.0f, 0, 0, 0);
        }
        if (!right_on) {
            draw_half(0.0f, 1.0f, 0, 0, 0);
        }
        return;
    }
    glBindTexture(GL_TEXTURE_2D, color_tex);
    set_nearest_clamp();
    draw_half(-1.0f, 0.0f, left_on ? s.r : 0, left_on ? s.g : 0, left_on ? s.b : 0);
    draw_half(0.0f, 1.0f, right_on ? s.r : 0, right_on ? s.g : 0, right_on ? s.b : 0);
}

void readback_halves(GLFWwindow* window) {
    int w = 0, h = 0;
    glfwGetFramebufferSize(window, &w, &h);
    if (w < 2 || h < 1) {
        return;
    }
    glPixelStorei(GL_PACK_ALIGNMENT, 1);
    GLubyte left[3] = {};
    GLubyte right[3] = {};
    glReadPixels(w / 4, h / 2, 1, 1, GL_RGB, GL_UNSIGNED_BYTE, left);
    glReadPixels((3 * w) / 4, h / 2, 1, 1, GL_RGB, GL_UNSIGNED_BYTE, right);
    std::printf("readback fb=%dx%d  left=(%u,%u,%u)  right=(%u,%u,%u)\n", w, h,
                left[0], left[1], left[2], right[0], right[1], right[2]);
}

std::string default_log_path() {
    const std::filesystem::path dir =
        std::filesystem::path(CHRONOLUME_ROOT) / "data" / "sessions";
    std::error_code ec;
    std::filesystem::create_directories(dir, ec);
    using clock = std::chrono::system_clock;
    const std::time_t t = clock::to_time_t(clock::now());
    std::tm tm{};
#if defined(_WIN32)
    localtime_s(&tm, &t);
#else
    localtime_r(&t, &tm);
#endif
    char name[64];
    std::snprintf(name, sizeof(name), "session_%04d%02d%02d_%02d%02d%02d.jsonl",
                  tm.tm_year + 1900, tm.tm_mon + 1, tm.tm_mday, tm.tm_hour,
                  tm.tm_min, tm.tm_sec);
    return (dir / name).string();
}

void update_title(GLFWwindow* window, const App& app) {
    const DeviceInfo info = app.device->info();
    char title[256];
    std::snprintf(title, sizeof(title),
                  "Chronolume stimulus  %s %s  eye=%s  bri=%d duty=%d film=%.0f",
                  app.stimulus.label, stimulus_desc(app).c_str(),
                  eye_name(app.stimulus.eye), info.brightness, info.duty_cycle, info.film);
    glfwSetWindowTitle(window, title);
}

void set_duty_manual(App* app, int requested) {
    requested = requested < 0 ? 0 : (requested > 100 ? 100 : requested);
    const bool ok = app->device->set_duty_cycle(requested);
    const DeviceInfo info = app->device->info();
    std::printf("duty requested=%d reported=%d bri=%d%s%s\n", requested, info.duty_cycle,
                info.brightness, ok ? "" : "  FAILED: ", ok ? "" : info.last_error.c_str());
    if (app->log.active()) {
        std::map<std::string, std::string> fields = stimulus_fields(*app);
        fields["requested_duty_cycle"] = std::to_string(requested);
        fields["ok"] = ok ? "1" : "0";
        app->log.event("duty", fields);
    }
    app->dirty = true;
}

bool key_pressed(GLFWwindow* window, int key) {
    static bool latch[512] = {};
    if (key < 0 || key >= 512) {
        return false;
    }
    const bool down = glfwGetKey(window, key) == GLFW_PRESS;
    const bool edge = down && !latch[key];
    latch[key] = down;
    return edge;
}

void list_monitors() {
    int count = 0;
    GLFWmonitor** monitors = glfwGetMonitors(&count);
    GLFWmonitor* primary = glfwGetPrimaryMonitor();
    for (int i = 0; i < count; ++i) {
        const GLFWvidmode* mode = glfwGetVideoMode(monitors[i]);
        int x = 0, y = 0;
        glfwGetMonitorPos(monitors[i], &x, &y);
        std::printf("monitor %d  %s  %dx%d@%d  pos=(%d,%d)%s\n", i, glfwGetMonitorName(monitors[i]),
                    mode ? mode->width : 0, mode ? mode->height : 0,
                    mode ? mode->refreshRate : 0, x, y,
                    monitors[i] == primary ? "  primary" : "");
    }
}

GLFWmonitor* fullscreen_monitor(const App& app) {
    if (app.monitor_index >= 0) {
        int count = 0;
        GLFWmonitor** monitors = glfwGetMonitors(&count);
        if (app.monitor_index < count) {
            return monitors[app.monitor_index];
        }
    }
    return glfwGetPrimaryMonitor();
}

void set_fullscreen(GLFWwindow* window, const App& app, bool on) {
    if (!on) {
        glfwSetWindowMonitor(window, nullptr, 80, 80, 1920, 540, 0);
        return;
    }
    GLFWmonitor* monitor = fullscreen_monitor(app);
    const GLFWvidmode* mode = glfwGetVideoMode(monitor);
    glfwSetWindowMonitor(window, monitor, 0, 0, mode->width, mode->height, mode->refreshRate);
#ifdef __APPLE__
    chronolume_set_device_rgb_color_space(window);
#endif
}

std::string json_str(const std::string& in) {
    std::string out = "\"";
    for (char c : in) {
        switch (c) {
            case '"':
                out += "\\\"";
                break;
            case '\\':
                out += "\\\\";
                break;
            case '\n':
                out += "\\n";
                break;
            case '\r':
                out += "\\r";
                break;
            case '\t':
                out += "\\t";
                break;
            default:
                if (static_cast<unsigned char>(c) < 0x20) {
                    char buf[8];
                    std::snprintf(buf, sizeof(buf), "\\u%04x", c);
                    out += buf;
                } else {
                    out += c;
                }
        }
    }
    return out + "\"";
}

std::string json_object(const std::map<std::string, std::string>& fields) {
    std::string out = "{";
    bool first = true;
    for (const auto& kv : fields) {
        if (!first) {
            out += ",";
        }
        first = false;
        out += json_str(kv.first) + ":" + json_str(kv.second);
    }
    return out + "}";
}

struct Readback {
    int fb_w = 0;
    int fb_h = 0;
    GLubyte left[3] = {};
    GLubyte right[3] = {};
    // Image stimuli: the whole framebuffer compared with the image (unshown halves black).
    bool image = false;
    bool image_match = false;
    long long image_mismatched = -1;  // pixels differing; -1 when the sizes differ
    std::string fb_hash;
};
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
int main(int argc, char** argv) {
    std::string backend = "mock";
    int control_port = 0;
    int monitor_index = -1;
    for (int i = 1; i < argc; ++i) {
        if (std::strcmp(argv[i], "--device") == 0 && i + 1 < argc) {
            backend = argv[++i];
        } else if (std::strcmp(argv[i], "--control-port") == 0 && i + 1 < argc) {
            if (!parse_int(argv[++i], 1, 65535, &control_port)) {
                std::fprintf(stderr, "--control-port must be 1-65535\n");
                return 1;
            }
        } else if (std::strcmp(argv[i], "--monitor") == 0 && i + 1 < argc) {
            if (!parse_int(argv[++i], 0, 63, &monitor_index)) {
                std::fprintf(stderr, "--monitor must be a monitor index (see startup list)\n");
                return 1;
            }
        } else if (std::strcmp(argv[i], "--help") == 0 || std::strcmp(argv[i], "-h") == 0) {
            std::puts("usage: chronolume_host [--device mock|viture] [--control-port N] [--monitor N]");
            return 0;
        }
    }

    App app;
    app.monitor_index = monitor_index;
    if (backend == "mock") {
        app.device = make_mock_device();
    } else if (backend == "viture") {
#ifdef CHRONOLUME_WITH_VITURE
        app.device = make_viture_device();
#else
        std::fprintf(stderr, "built without VITURE SDK\n");
        return 1;
#endif
    } else {
        std::fprintf(stderr, "unknown --device %s (use mock or viture)\n", backend.c_str());
        return 1;
    }

    if (!app.device->open()) {
        const DeviceInfo info = app.device->info();
        std::fprintf(stderr, "device open failed: %s\n", info.last_error.c_str());
        return 1;
    }

    print_keys();
    print_info(app.device->info());
    stimulus_set_rgb(&app.stimulus, 0, 0, 0, "black");

    if (!glfwInit()) {
        std::fprintf(stderr, "glfwInit failed\n");
        return 1;
    }
    list_monitors();
    if (control_port > 0) {
        std::string err;
        if (!app.control.start(static_cast<uint16_t>(control_port), &err)) {
            std::fprintf(stderr, "control server failed: %s\n", err.c_str());
            glfwTerminate();
            return 1;
        }
        std::printf("control listening on 127.0.0.1:%d\n", control_port);
    }
    glfwWindowHint(GLFW_CONTEXT_VERSION_MAJOR, 2);
    glfwWindowHint(GLFW_CONTEXT_VERSION_MINOR, 1);
    glfwWindowHint(GLFW_COCOA_RETINA_FRAMEBUFFER, GLFW_FALSE);
    glfwWindowHint(GLFW_SRGB_CAPABLE, GLFW_FALSE);
    glfwWindowHint(GLFW_DEPTH_BITS, 0);
    // A fullscreen window minimizes on focus loss by default; the stimulus must stay up while the
    // operator works in the console on another monitor.
    glfwWindowHint(GLFW_AUTO_ICONIFY, GLFW_FALSE);

    GLFWwindow* window = glfwCreateWindow(1920, 540, "Chronolume stimulus", nullptr, nullptr);
    if (!window) {
        std::fprintf(stderr, "glfwCreateWindow failed\n");
        glfwTerminate();
        return 1;
    }
    glfwMakeContextCurrent(window);
    glfwSwapInterval(1);
#ifdef __APPLE__
    chronolume_set_device_rgb_color_space(window);
#endif

    GLuint tex = 0;
    glGenTextures(1, &tex);
    GLuint image_tex = 0;
    glGenTextures(1, &image_tex);
    app.image_tex = image_tex;
    glBindTexture(GL_TEXTURE_2D, tex);
    glMatrixMode(GL_PROJECTION);
    glLoadIdentity();
    glMatrixMode(GL_MODELVIEW);
    glLoadIdentity();
    update_title(window, app);

    while (!glfwWindowShouldClose(window)) {
        glfwPollEvents();
        if (key_pressed(window, GLFW_KEY_ESCAPE)) {
            break;
        }

        const int ladder_keys[] = {GLFW_KEY_0, GLFW_KEY_1, GLFW_KEY_2, GLFW_KEY_3,
                                   GLFW_KEY_4, GLFW_KEY_5, GLFW_KEY_6};
        for (int i = 0; i < 7; ++i) {
            if (key_pressed(window, ladder_keys[i])) {
                stimulus_set_blue_level(&app.stimulus, kBlueLadder[i]);
                app.dirty = true;
            }
        }
        if (key_pressed(window, GLFW_KEY_K)) {
            stimulus_set_rgb(&app.stimulus, 0, 0, 0, "black");
            app.dirty = true;
        }
        if (key_pressed(window, GLFW_KEY_R)) {
            stimulus_set_rgb(&app.stimulus, 255, 0, 0, "red");
            app.dirty = true;
        }
        if (key_pressed(window, GLFW_KEY_G)) {
            stimulus_set_rgb(&app.stimulus, 0, 255, 0, "green");
            app.dirty = true;
        }
        if (key_pressed(window, GLFW_KEY_B)) {
            stimulus_set_rgb(&app.stimulus, 0, 0, 255, "blue");
            app.dirty = true;
        }
        if (key_pressed(window, GLFW_KEY_W)) {
            stimulus_set_rgb(&app.stimulus, 255, 255, 255, "white");
            app.dirty = true;
        }
        if (key_pressed(window, GLFW_KEY_F1)) {
            app.stimulus.eye = EyeTarget::Left;
            app.dirty = true;
        }
        if (key_pressed(window, GLFW_KEY_F2)) {
            app.stimulus.eye = EyeTarget::Right;
            app.dirty = true;
        }
        if (key_pressed(window, GLFW_KEY_F3)) {
            app.stimulus.eye = EyeTarget::Both;
            app.dirty = true;
        }
        if (key_pressed(window, GLFW_KEY_LEFT_BRACKET)) {
            app.device->set_brightness(app.device->info().brightness - 1);
            app.dirty = true;
        }
        if (key_pressed(window, GLFW_KEY_RIGHT_BRACKET)) {
            app.device->set_brightness(app.device->info().brightness + 1);
            app.dirty = true;
        }
        if (key_pressed(window, GLFW_KEY_COMMA)) {
            set_duty_manual(&app, app.device->info().duty_cycle - 10);
        }
        if (key_pressed(window, GLFW_KEY_PERIOD)) {
            set_duty_manual(&app, app.device->info().duty_cycle + 10);
        }
        if (key_pressed(window, GLFW_KEY_9)) {
            set_duty_manual(&app, 98);
        }
        if (key_pressed(window, GLFW_KEY_F)) {
            const float film = app.device->info().film;
            app.device->set_film(film > 0.0f ? 0.0f : 1.0f);
            app.dirty = true;
        }
        if (key_pressed(window, GLFW_KEY_S)) {
            if (app.log.active()) {
                const std::string p = app.log.path();
                app.log.stop();
                std::printf("session stopped %s\n", p.c_str());
            } else {
                const std::string p = default_log_path();
                if (app.log.start(p)) {
                    const DeviceInfo info = app.device->info();
                    app.log.event("capability", {
                        {"backend", info.backend},
                        {"device", info.market_name},
                        {"firmware", info.firmware},
                        {"product_id", std::to_string(info.product_id)},
                    });
                    log_stimulus(&app);
                    std::printf("session started %s\n", p.c_str());
                } else {
                    std::fprintf(stderr, "could not write %s\n", p.c_str());
                }
            }
        }
        if (key_pressed(window, GLFW_KEY_D)) {
            print_info(app.device->info());
            if (app.log.active()) {
                app.log.event("capability_dump", stimulus_fields(app));
            }
        }
        if (key_pressed(window, GLFW_KEY_V)) {
            readback_halves(window);
            if (app.log.active()) {
                app.log.event("readback", stimulus_fields(app));
            }
        }
        if (key_pressed(window, GLFW_KEY_P)) {
            set_fullscreen(window, app, glfwGetWindowMonitor(window) == nullptr);
        }

        std::vector<CommandResult> results;
        bool quit = false;
        for (const std::string& line : app.control.poll()) {
            results.push_back(run_command(&app, window, line));
            quit = quit || results.back().quit;
        }

        const int wear = app.device->info().wear_status;
        if (wear != app.last_wear) {
            std::printf("wear %d\n", wear);
            if (app.log.active()) {
                std::map<std::string, std::string> fields = stimulus_fields(app);
                fields["previous_wear"] = std::to_string(app.last_wear);
                app.log.event("wear", fields);
            }
            app.last_wear = wear;
        }

        if (app.dirty) {
            log_stimulus(&app);
            update_title(window, app);
            app.dirty = false;
        }
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

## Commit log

2026-10-04 Initialize repo, 3d assets complete, awaiting final code/data
    [UPRtek MK350S.step]
2026-10-05 Publish the stimulus host, UPRtek pipeline, calibration package, and measurement data.
    [ANCHOR_00.csv, ANCHOR_01.csv, ANCHOR_02.csv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]
